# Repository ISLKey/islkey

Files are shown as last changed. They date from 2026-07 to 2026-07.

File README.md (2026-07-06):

# ISLKey

Access-control platform by **ISL Technologies** — ESP32-based door controllers with a
Windows flasher/commissioning tool and a companion mobile app.

## Repository layout

| Path | What it is | Stack |
|---|---|---|
| `islkey-firmware/` | Door-controller firmware — 4 board targets (relay-board, devkit, ttgo, wt32-eth01). Inputs (exit/door/fire/tamper), relay-driven lock, cloud HMAC device-auth, NimBLE. | ESP32 / PlatformIO / Arduino |
| `islkey-flasher/`  | Desktop flasher + serial commissioning tool. Flashes merged full-flash images at `0x0`, assigns serials, writes WiFi/API config over serial. | Electron / Node.js |
| `islkey-app/` | Companion door-access mobile app (NFC tap → resolve → unlock). | Flutter |
| `kicad/` | KiCad 8 schematic for the TTGO controller (inputs, relay lock output, monitored fire link, backup power). | KiCad |
| `wordpress/` | Drop-in integration notes for the isl-key WordPress plugin (device API / provisioning). | — |
| `make_wiring_diagram.py` | Generates the 4-sheet wiring/pinout PDF (`ISLKey-Wiring-Diagram.pdf`). | Python / matplotlib |
| `make_kicad_schematic.py` | Generates `kicad/ISLKey.kicad_sch` from source. | Python |

## Building

- **Firmware:** `cd islkey-firmware && python -m platformio run` (per-env in `platformio.ini`).
  After a rebuild, regenerate the merged images with `esptool merge_bin` (see below) — the
  flasher writes a **merged full-flash image at `0x0`**; a raw app image boot-loops the board.
- **Flasher:** `cd islkey-flasher && npm install && npm start` (or `npm run build` for the installer).
- **App:** `cd islkey-app && flutter pub get && flutter run`.

## Hardware notes

- On the **TTGO T-Display** target the TFT occupies GPIO 4/5/16/18/19/23, so door I/O is
  remapped: inputs GPIO 13/25/26/27, relays GPIO 32/33.
- The lock is switched via an **external opto-isolated relay module** (COM/NC), with a
  single **volt-free fire N/C contact in series** (hardware release, controller-independent)
  that is **opto-monitored to GPIO26** for fire detection + cable supervision. See `kicad/`
  and the wiring PDF.

## Not in this repo

Build artifacts (`.pio/`, `node_modules/`, Flutter `build/`, installer `dist/`) and
**operational secrets** — the per-device serial register / AP passwords (`islkey-flasher/serials/`)
and any real `.islkey` provisioning configs — are git-ignored.

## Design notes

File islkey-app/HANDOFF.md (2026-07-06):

# ISLKey Flutter — Developer Handoff

The **ISLKey** door-access app for ISLKey users (door holders). Built in the same
ecosystem and on the same architecture as **ISLShift** (the staff clock-in app).

Last updated: 2026-06-21.

---

## Current status

✅ **Builds on Android.** `flutter build apk --debug` → `build/app/outputs/flutter-apk/app-debug.apk`.
- `flutter analyze` → **0 errors / 0 warnings** (only cosmetic `withOpacity` / `prefer_const`
  deprecation *infos* remain — identical class of non-blocking notices to ISLShift).
- **Not yet run on a physical device.** NFC requires real hardware (emulators have no NFC);
  no Android device was connected at build time. Install with:
  ```
  flutter build apk --debug --target-platform android-arm64
  adb -s <deviceId> install -r -d build/app/outputs/flutter-apk/app-debug.apk
  ```
- iOS scaffolding exists but has not been built (no macOS/Xcode here). The NFC Tag Reading
  capability + `NFCReaderUsageDescription` Info.plist key must be added before an iOS build.

## Build environment

Same as ISLShift: Flutter 3.44.2 (`C:\src\flutter`), Android Studio JBR as `JAVA_HOME`,
`ANDROID_HOME` = `…\AppData\Local\Android\Sdk`. Package / applicationId:
**`com.isltechnologies.islkey`**.

Build workarounds baked into the repo (do not undo):
- `android/build.gradle.kts` forces every plugin subproject to `compileSdk = 36` via an
  `afterEvaluate` block registered **before** `evaluationDependsOn(":app")` — `nfc_manager`
  hardcodes an older compileSdk than its AndroidX deps require. Moving the block after
  `evaluationDependsOn` throws "project already evaluated".
- `AndroidManifest.xml` requests `INTERNET` + `NFC`, declares `android.hardware.nfc` as
  **not required** (installs on non-NFC phones), and **deliberately has no NFC tag-dispatch
  intent filters** — those make Android launch a second app instance on a stray tap. Tags are
  read via `nfc_manager` reader mode while the scan screen is open.

---

## Architecture (mirrors ISLShift)

```
lib/
  main.dart                     ProviderScope + MaterialApp, branding-driven theme
  theme.dart                    ISL palette + per-customer brand colour
  models/                       branding_data, user_profile, door, credential,
                                access_event, linked_site, unlock_result
  services/
    api_service.dart            HTTP; unwraps the ISL Core { ok, data } envelope
    nfc_service.dart            reader-mode scan → uppercase hex UID (no colons)
    secure_storage_service.dart token + profile + linked sites + offline caches
  providers/
    auth_provider.dart          setup / PIN login / sign out (Riverpod Notifier)
    doors_provider.dart         doors+credentials list, caching, unlock state machine
    sites_provider.dart         linked sites
  screens/                      splash, login, setup, home, nfc_scan,
                                unlock_result, history, profile, link_site
  widgets/shared_widgets.dart   logo, PIN pad, NFC pulse ring, access tile, etc.
```

Backend: `https://i-s-l.co.uk/wp-json`, namespace `islkey/v1`. Bearer token
(`Authorization: Bearer …`, query-param `?_isl_token=` fallback), 12-hour expiry → 401 →
re-auth with PIN. **All ISLKey responses are wrapped as `{ "ok": true, "data": {…} }`** —
`ApiService._handleResponse` unwraps `data` (this differs from ISLShift, which returned the
payload at the top level).

### Endpoints wired up (Layer 1 — App API)
`POST /invite/accept` · `POST /auth` · `POST /site/link` · `GET /tags/resolve` ·
`GET /me/doors` · `GET /me/credentials` · `GET /me/log` · `POST /doors/{id}/unlock`.
Customer branding comes from the shared ISL Core endpoint `GET /isl/v1/branding/{slug}`
(best-effort; falls back to ISLKey defaults so login never blocks on it).

### The unlock flow
1. **Primary (NFC, cloud-mediated):** tap phone to the door tag → read UID →
   `GET /tags/resolve?serial=` → verify the door is in the user's `/me/doors` list →
   `POST /doors/{id}/unlock` (method `NFC_TAP_CLOUD`) → backend queues the command to the
   ESP32 → show "Unlock sent" (the door opens when the ESP32 next polls; no push exists yet).
2. **Direct:** each door card also has an Unlock button that calls `/doors/{id}/unlock`
   directly for an authenticated user already at/near the door.

Unlock is blocked client-side when a door has no controller (`device_uuid == null`) or its
`fire_alarm_state == "ACTIVE"`; the backend re-checks regardless (403 / 422 / 404 handled).

---

## Deliberately NOT built (per the handover brief)

- **BLE direct-unlock fallback** — the brief marks this as the single blocking dependency:
  the ESP32 BLE service UUID and the signed offline-unlock token format must be agreed between
  firmware and app first. `/me/doors` + `/me/credentials` are already cached locally
  (`SecureStorageService`) so the cache the BLE path needs is in place. Add a `ble_service.dart`
  + an offline-detection branch in `doors_provider.resolveAndUnlock` once the format is agreed.
- **Change PIN** — the ISLKey API reference defines no `/me/pin` endpoint, so the profile
  screen omits it (add a tile once the backend exposes one).
- **Push notifications** — backend has no FCM/APNs yet; the app uses the timeout approach
  ("Unlock sent" after the queue accepts the command).

## Outstanding TODOs

1. **Release signing** — release builds currently use the debug key. Add a real keystore
   before shipping.
2. **App identity** — default Flutter launcher icon is still in place; add the ISLKey icon.
3. **On-device verification** — run the full flow (setup → PIN → tap-to-unlock → history) on a
   physical NFC Android device with a registered test tag (`58E104DD`, site `TE2001`).
4. **iOS** — add NFC capability + Info.plist usage string, then build.

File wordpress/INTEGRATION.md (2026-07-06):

# ISLKey `.islkey` Config Export — WordPress Integration

This adds a **Download .islkey Config File** button to the ISLKey provisioning-token
screen. The file is plain JSON consumed by the ISLKey Flasher's **Load .islkey File**
button. It is mechanism-agnostic — it only emits config; the flasher writes it to the
device over the commissioning serial link.

> The ISLKey WordPress plugin is **not part of this workspace** (it lives on the
> customer's site), so these changes are provided as drop-in snippets to merge into
> your `isl-key` plugin. They match the schema the new flasher expects.

Files to edit in the `isl-key` plugin:
- `admin/class-islkey-admin.php`
- `admin/views/devices.php`

---

## 1. `admin/class-islkey-admin.php`

### 1a — Register the handler (in `init()`, beside the other `admin_post` handlers)

```php
add_action( 'admin_post_islkey_download_config', array( __CLASS__, 'handle_download_config' ) );
```

### 1b — Store `board_type` when a token is generated

In `handle_generate_token()`, after:
```php
$expiry_hours = (int) ( $_POST['expiry_hours'] ?? 24 );
```
add:
```php
$board_type = sanitize_key( $_POST['board_type'] ?? 'relay-board' );
```
and add `board_type` to the existing `set_transient( 'islkey_fresh_token_' . get_current_user_id(), [...] )` array:
```php
'board_type' => $board_type,
```

### 1c — Add the download handler method (after `handle_generate_token()`)

```php
public static function handle_download_config() {
    check_admin_referer( 'islkey_download_config' );
    if ( ! current_user_can( 'manage_options' ) ) wp_die( 'Forbidden' );

    global $wpdb;

    $token       = sanitize_text_field( $_POST['token']       ?? '' );
    $customer_id = (int) ( $_POST['customer_id'] ?? 0 );
    $board_type  = sanitize_key( $_POST['board_type'] ?? 'relay-board' );

    // Validate token: exists, belongs to this customer, unconsumed, unexpired
    $pt = $wpdb->get_row( $wpdb->prepare(
        "SELECT * FROM `{$wpdb->prefix}islkey_provisioning_tokens`
         WHERE token = %s AND customer_id = %d AND consumed = 0 AND expires_at > NOW()",
        $token, $customer_id
    ) );
    if ( ! $pt ) {
        wp_die( 'Token not found, already consumed, or expired.' );
    }

    $door      = $pt->door_id ? ISLKey_Doors::get( $pt->door_id, $customer_id ) : null;
    $site      = ISLKey_Sites::get( $pt->site_id, $customer_id );
    $site_code = $site ? ( $site->site_code ?? sanitize_key( $site->site_name ) ) : '';

    $current_user = wp_get_current_user();

    $config = array(
        'islkey_config_version' => '1.0',
        'generated_at'          => gmdate( 'Y-m-d\TH:i:s\Z' ),
        'generated_by'          => 'ISL Admin — ' . $current_user->user_email,
        'expires_at'            => gmdate( 'Y-m-d\TH:i:s\Z', strtotime( $pt->expires_at ) ),

        'api' => array(
            'url'   => untrailingslashit( get_site_url() ),
            'token' => $token,
        ),

        'device' => array(
            'serial_number' => '',   // Flasher assigns from its own counter at flash time
            'board_type'    => $board_type,
            'door_name'     => $door ? $door->door_name : ( $site ? $site->site_name . ' Door' : 'Door' ),
            'site_name'     => $site ? $site->site_name : '',
            'site_code'     => $site_code,
            'door_id'       => $pt->door_id ? (int) $pt->door_id : 0,
            'site_id'       => $pt->site_id ? (int) $pt->site_id : 0,
            'customer_id'   => (int) $customer_id,
            'zone'          => $door ? ( $door->zone ?? '' ) : '',
        ),

        // Sensible defaults. The current device firmware applies api/door/site from
        // this file at commissioning; inputs/relays/door_behaviour use firmware
        // defaults and are overridable on the device provisioning page. (Panic input
        // types 5–7 require the separate "Protocols" firmware build.)
        'inputs' => array(
            'input_1_function' => 1, 'input_1_logic' => 1,
            'input_2_function' => 2, 'input_2_logic' => 0,
            'input_3_function' => 5, 'input_3_logic' => 1,
            'input_4_function' => 6, 'input_4_logic' => 1,
        ),
        'relays' => array(
            'relay_1_function' => 1, 'relay_1_pulse_ms' => 5000, 'relay_1_active_high' => true,
            'relay_2_function' => 0, 'relay_2_pulse_ms' => 2000, 'relay_2_active_high' => true,
        ),
        'door_behaviour' => array(
            'held_open_secs' => 60, 'forced_entry_detect' => true,
        ),
    );

    $safe_door = preg_replace( '/[^a-zA-Z0-9]+/', '', str_replace( ' ', '', $config['device']['door_name'] ) );
    $safe_site = preg_replace( '/[^a-zA-Z0-9]+/', '', str_replace( ' ', '', $config['device']['site_code'] ?: $config['device']['site_name'] ) );
    $filename  = "ISLKey-{$safe_site}-{$safe_door}-" . date( 'Ymd' ) . ".islkey";

    nocache_headers();
    header( 'Content-Type: application/json; charset=utf-8' );
    header( 'Content-Disposition: attachment; filename="' . $filename . '"' );
    header( 'X-Content-Type-Options: nosniff' );
    echo wp_json_encode( $config, JSON_PRETTY_PRINT | JSON_UNESCAPED_SLASHES );
    exit;
}
```

---

## 2. `admin/views/devices.php`

### 2a — Board-type selector in the Generate-Token form (before the submit button)

```php
<tr>
    <th>Board Type</th>
    <td>
        <select name="board_type" class="regular-text">
            <option value="relay-board">ISLKey Relay Board (WROOM dual relay)</option>
            <option value="devkit">ESP32 DevKit V1 (testing)</option>
            <option value="ttgo">TTGO T-Display (with LCD)</option>
            <option value="wt32-eth01">WT32-ETH01 (Ethernet + PoE)</option>
        </select>
    </td>
</tr>
```

### 2b — Download button in the fresh-token panel (after the "Device API Token" row)

```php
<tr>
    <th>Config File</th>
    <td>
        <form method="post" action="<?php echo esc_url( admin_url( 'admin-post.php' ) ); ?>" style="display:inline;">
            <?php wp_nonce_field( 'islkey_download_config' ); ?>
            <input type="hidden" name="action"      value="islkey_download_config">
            <input type="hidden" name="token"       value="<?php echo esc_attr( $fresh_token['token'] ); ?>">
            <input type="hidden" name="customer_id" value="<?php echo esc_attr( $customer_id ); ?>">
            <input type="hidden" name="board_type"  value="<?php echo esc_attr( $fresh_token['board_type'] ?? 'relay-board' ); ?>">
            <button type="submit" class="button button-primary">⬇ Download .islkey Config File</button>
        </form>
        <p class="description">
            Load this file into the ISLKey Flasher. It pre-populates board type, API URL,
            token, door name and site code — only WiFi is entered on the device.
        </p>
    </td>
</tr>
```

---

## Notes for the new firmware/flasher

- `device.serial_number` is intentionally `""` — the flasher assigns the serial from its
  local counter (`serials/next-serial.txt`) at flash time and logs it to the asset register.
- The flasher writes `api.url`, `api.token`, `device.door_name`, `device.site_code` (plus the
  generated serial + AP password) to the device over the serial commissioning link
  (`ISLKEY-PROV:{json}` → `ISLKEY-ACK`). The device stores them in NVS and pre-fills its
  provisioning page, so the installer only enters WiFi SSID + password.
- This export does **not** use the old `buildNVSImage` / `checkFlasherPayload` path from the
  v1.0 build guide — that was for the previous firmware and has been superseded.

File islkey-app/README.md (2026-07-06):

# islkey

A new Flutter project.

## Getting Started

This project is a starting point for a Flutter application.

A few resources to get you started if this is your first Flutter project:

- [Learn Flutter](https://docs.flutter.dev/get-started/learn-flutter)
- [Write your first Flutter app](https://docs.flutter.dev/get-started/codelab)
- [Flutter learning resources](https://docs.flutter.dev/reference/learning-resources)

For help getting started with Flutter development, view the
[online documentation](https://docs.flutter.dev/), which offers tutorials,
samples, guidance on mobile development, and a full API reference.

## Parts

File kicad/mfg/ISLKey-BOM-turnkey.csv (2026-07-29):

Item | Refs | Qty | Value | Footprint | Type | Manufacturer | MPN | Distributor | Distributor PN / Link | Notes
1 | R1,R3,R6,R7,R8 | 5 | 1k | R_0805 | SMD | Yageo | RC0805FR-071KL | LCSC | C17513 | 1% 0805 thick film; Digikey 311-1.00KCRCT-ND
2 | R2,R4 | 2 | 10k | R_0805 | SMD | Yageo | RC0805FR-0710KL | LCSC | C17414 | 1% 0805
3 | R5 | 1 | 2k2 | R_0805 | SMD | Yageo | RC0805FR-072K2L | LCSC | C4190 | 1% 0805 (opto LED series)
4 | C2,C3,C6 | 3 | 100nF | C_0805 | SMD | Samsung | CL21B104KBCNNNC | LCSC | C1525 | 50V X7R decoupling
5 | C1 | 1 | 100uF 16V | CP_Elec_6.3x5.3 | SMD | Panasonic | EEE-1CA101P | Digikey | PCE3903CT-ND | SMD alu 6.3mm
6 | C5 | 1 | 100uF 25V | CP_Elec_6.3x5.3 | SMD | Panasonic | EEE-1EA101P | Digikey | PCE3915CT-ND | SMD alu 6.3mm (12V bulk)
7 | C4 | 1 | 100uF 100V | CP_Elec_10x10.5 | SMD | Nichicon | UCM2A101MNL1GS | Digikey | 493-UCM2A101MNL1GS | 100V SMD alu 10mm can (bridge bulk); verify height/dia vs footprint
8 | D1,D2 | 2 | 1N4007 (M7) | D_SMA | SMD | Diodes Inc | M7-13-F | LCSC | C95872 | 1A 1000V SMA (relay flyback)
9 | D3 | 1 | PWR (red) | LED_0805 | SMD | Kingbright | APT2012SURCK | LCSC | C2286 | Power indicator LED (red)
10 | D4,D5 | 2 | GRN | LED_0805 | SMD | Kingbright | APT2012LZGCK | LCSC | C72043 | Relay-status LEDs (green)
11 | Q1,Q2 | 2 | PN2222A | TO-92_Inline | THT | onsemi | PN2222ABU | Digikey | PN2222ABU-ND | NPN relay driver
12 | K1,K2 | 2 | SRD-05VDC-SL-C | Relay_SPDT_SANYOU_SRD | THT | Songle | SRD-05VDC-SL-C | LCSC | C39487 | 5V coil SPDT 10A relay
13 | U1 | 1 | PC817 | DIP-4_W7.62mm | THT | LiteOn | LTV-817 | LCSC | C6553 | Optocoupler (fire monitor); Sharp PC817 equivalent
14 | U3 | 1 | TMR 10-2412WIR | Converter_DCDC_TRACO_TMR10 | THT | Traco Power | TMR 10-2412WIR | Digikey | https://www.digikey.com/short/tmr10-2412wir | 9-36V -> iso 12V 10W SIP-8; Mouser also
15 | U4 | 1 | TSR 1-2450 | Converter_DCDC_TRACO_TSR-1 | THT | Traco Power | TSR 1-2450 | LCSC | C6886877 | 12->5V 1A SIP-3 buck; Digikey too
16 | U5 | 1 | DS3231SN | SOIC-16W_7.5x10.3 | SMD | Analog Devices (Maxim) | DS3231SN# | Digikey | DS3231SN#-ND | NOTE: 16-SOIC part is DS3231SN (schematic label says DS3231M; the SO-8 'M' does NOT fit this footprint)
17 | BR1 | 1 | KBU4M | Diode_Bridge_Vishay_KBU | THT | Comchip | KBU4M-G | Digikey | 641-1373-ND | 4A 1000V bridge rectifier
18 | F1 (clips) | 2 | Fuse clip 5x20 | Fuseholder_Clip-5x20mm_Keystone_3512 | THT | Keystone | 3512 | Digikey | 36-3512-ND | TWO clips make one holder (F1)
19 | F1 (fuse) | 1 | T2A 5x20 | - | - | Littelfuse | 0217002.MXP | Digikey | F2452-ND | 2A slow-blow 5x20mm glass fuse
20 | BT1 | 1 | 18650 holder | BatteryHolder_Keystone_1042 | SMD | Keystone | 1042 | Digikey | 36-1042-ND | SMT 1x18650 holder
21 | BT3 | 1 | CR2032 holder | BatteryHolder_Keystone_3002 | SMD | Keystone | 3002 | Digikey | 36-3002-ND | SMT CR2032 retainer (RTC backup)
22 | J3,J4,J5,J8,J10,J11 | 6 | Screw term 2-pin | TerminalBlock MKDS 5.08 1x02 | THT | Phoenix Contact | MKDS 1,5/ 2-5.08 (1715721) | Digikey | 277-1247-ND | 5.08mm 2-way 17.5A
23 | J6,J7 | 2 | Screw term 3-pin | TerminalBlock MKDS 5.08 1x03 | THT | Phoenix Contact | MKDS 1,5/ 3-5.08 (1715734) | Digikey | 277-1248-ND | 5.08mm 3-way (relay COM/NO/NC)
24 | J9,J13,J15 | 3 | Header 1x02 2.54 | PinHeader_1x02_2.54mm | THT | Wurth | 61300211121 | LCSC | C124378 | 2-pin 2.54mm header
25 | J9,J15 shunts | 2 | Jumper shunt | - | - | Sullins | SPC02SYAN | Digikey | S9337-ND | 2.54mm jumper caps for the FIRE LINK + DCDC ON headers
26 | H1-H4 | 4 | M3 mount | MountingHole_3.2mm | Hardware | - | M3 screw/standoff | - | - | Not populated by assembler; mechanical M3
NOTE |  |  |  |  |  |  |  |  |  | M1 (TTGO T-Display) intentionally omitted - customer-sourced, fits into headers post-assembly. Distributor PNs are indicative; confirm current stock/PN before ordering.

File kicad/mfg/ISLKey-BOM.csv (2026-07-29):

Refs | Value | Footprint | Qty
BR1 | KBU4M (4A) | Diode_THT:Diode_Bridge_Vishay_KBU | 1
BT1 | 18650 | Battery:BatteryHolder_Keystone_1042_1x18650 | 1
BT3 | CR2032 | Battery:BatteryHolder_Keystone_3002_1x2032 | 1
C1 | 100uF/16V | Capacitor_SMD:CP_Elec_6.3x5.3 | 1
C2,C3,C6 | 100nF | Capacitor_SMD:C_0805_2012Metric | 3
C4 | 100uF/100V | Capacitor_SMD:CP_Elec_10x10.5 | 1
C5 | 100uF/25V | Capacitor_SMD:CP_Elec_6.3x5.3 | 1
D1,D2 | 1N4007 | Diode_SMD:D_SMA | 2
D3 | PWR | LED_SMD:LED_0805_2012Metric | 1
D4,D5 | GRN | LED_SMD:LED_0805_2012Metric | 2
F1 | T2A | Fuse:Fuseholder_Clip-5x20mm_Keystone_3512_Inline_P23.62x7.27mm_D1.02x1.57mm_Horizontal | 1
J3 | Exit btn | TerminalBlock_Phoenix:TerminalBlock_Phoenix_MKDS-1,5-2-5.08_1x02_P5.08mm_Horizontal | 1
J4 | Door contact | TerminalBlock_Phoenix:TerminalBlock_Phoenix_MKDS-1,5-2-5.08_1x02_P5.08mm_Horizontal | 1
J5 | Tamper | TerminalBlock_Phoenix:TerminalBlock_Phoenix_MKDS-1,5-2-5.08_1x02_P5.08mm_Horizontal | 1
J6 | LOCK COM/NO/NC | TerminalBlock_Phoenix:TerminalBlock_Phoenix_MKDS-1,5-3-5.08_1x03_P5.08mm_Horizontal | 1
J7 | AUX COM/NO/NC | TerminalBlock_Phoenix:TerminalBlock_Phoenix_MKDS-1,5-3-5.08_1x03_P5.08mm_Horizontal | 1
J8 | Fire volt-free | TerminalBlock_Phoenix:TerminalBlock_Phoenix_MKDS-1,5-2-5.08_1x02_P5.08mm_Horizontal | 1
J9 | Fire link COM-Fire | Connector_PinHeader_2.54mm:PinHeader_1x02_P2.54mm_Vertical | 1
J10 | 5-60V AC/DC IN | TerminalBlock_Phoenix:TerminalBlock_Phoenix_MKDS-3-2-5.08_1x02_P5.08mm_Horizontal | 1
J11 | 12V OUT (lock/aux) | TerminalBlock_Phoenix:TerminalBlock_Phoenix_MKDS-3-2-5.08_1x02_P5.08mm_Horizontal | 1
J13 | TTGO batt pads | Connector_PinHeader_2.54mm:PinHeader_1x02_P2.54mm_Vertical | 1
J15 | DCDC ON link (Ctrl-+Vin) | Connector_PinHeader_2.54mm:PinHeader_1x02_P2.54mm_Vertical | 1
K1,K2 | SRD-05VDC-SL-C | Relay_THT:Relay_SPDT_SANYOU_SRD_Series_Form_C | 2
M1 | TTGO T-Display | ISLKey:TTGO_ESP32_TDisplay_v1.1 | 1
Q1,Q2 | PN2222A | Package_TO_SOT_THT:TO-92_Inline | 2
R1,R3,R6-R8 | 1k | Resistor_SMD:R_0805_2012Metric | 5
R2,R4 | 10k | Resistor_SMD:R_0805_2012Metric | 2
R5 | 2k2 | Resistor_SMD:R_0805_2012Metric | 1
U1 | PC817 | Package_DIP:DIP-4_W7.62mm | 1
U3 | TMR10-2412WIR | Converter_DCDC:Converter_DCDC_TRACO_TMR10-24xxWIR_48xxWIR_72xxWIR_THT | 1
U4 | TSR-1-2450 | Converter_DCDC:Converter_DCDC_TRACO_TSR-1_THT | 1
U5 | DS3231M | Package_SO:SOIC-16W_7.5x10.3mm_P1.27mm | 1

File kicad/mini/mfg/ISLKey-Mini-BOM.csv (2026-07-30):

Item | Designator | Qty | Value | Footprint | Manufacturer | MPN | Supplier | Supplier PN | Placement | Notes
1 | R1,R4,R7 | 3 | 1k | R_0805 | Yageo | RC0805FR-071KL | LCSC | C17513 | SMD | 1% 1/8W (R4=PWR-LED, R7=relay-LED, R1=relay-base)
2 | R2,R6 | 2 | 10k | R_0805 | Yageo | RC0805FR-0710KL | LCSC | C17414 | SMD | R2=base pulldown, R6=FB bottom
3 | R5 | 1 | 53.6k | R_0805 | Yageo | RC0805FR-0753K6L | Digikey | 311-53.6KCRCT-ND | SMD | buck FB top divider (5V out)
4 | C1,C2,C5,C6 | 4 | 100nF | C_0805 | Samsung | CL21B104KBCNNNC | LCSC | C1525 | SMD | 50V X7R decoupling
5 | C4 | 1 | 22uF/25V | CP_Elec_6.3x5.3 | Panasonic | EEE-1EA220P | Digikey | PCE3908CT-ND | SMD | SMD alu, bridge bulk
6 | C7 | 1 | 22uF/16V | CP_Elec_6.3x5.3 | Panasonic | EEE-1CA220P | Digikey | PCE3903CT-ND | SMD | SMD alu, 5V out
7 | L1 | 1 | 4.7uH | L_6.3x6.3_H3 | Sunlord | SWPA6045S4R7MT | LCSC | C167218 | SMD | >=2A shielded power inductor
8 | U2 | 1 | AP63203WU | TSOT-23-6 | Diodes Inc | AP63203WU-7 | Digikey | AP63203WU-7DICT-ND | SMD | 3.8-32V -> 5V 2A sync buck
9 | BR1 | 1 | ABS10 | Diode_Bridge_Diotec_ABS | Diotec | ABS10 | LCSC | C86089 | SMD | 1A 1000V SMD bridge (AC or DC in)
10 | F1 | 1 | 500mA PTC | Fuse_1812 | Bourns | MF-MSMF050-2 | Digikey | MF-MSMF050-2CT-ND | SMD | resettable PTC 1812
11 | D1 | 1 | 1N4148 | SOD-123 | Diodes Inc | 1N4148W-7-F | LCSC | C81598 | SMD | relay-coil flyback
12 | Q1 | 1 | MMBT2222A | SOT-23 | onsemi | MMBT2222ALT1G | LCSC | C8286 | SMD | relay driver NPN
13 | D3 | 1 | PWR (red) | LED_0805 | Kingbright | APT2012SURCK | LCSC | C2286 | SMD | power indicator LED
14 | D4 | 1 | GRN | LED_0805 | Kingbright | APT2012LZGCK | LCSC | C72043 | SMD | relay-status LED
15 | K1 | 1 | G6E (2A) | Relay_SPDT_Omron_G6E | Omron | G6E-134P-ST-US DC5 | Digikey | Z8917-ND | THT | SPDT 2A -- ORDER THE DC5 (5V coil) VARIANT
16 | J1,J3 | 2 | Term 2-pin | PT-1,5/2-3.5-H | Phoenix Contact | PT 1,5/2-3,5-H (1935161) | Digikey | 277-9524-ND | THT | 3.5mm horizontal-entry (J1=12V in, J3=EXIT)
17 | J2 | 1 | Term 3-pin | PT-1,5/3-3.5-H | Phoenix Contact | PT 1,5/3-3,5-H (1935174) | Digikey | 277-9525-ND | THT | 3.5mm horizontal-entry (LOCK COM/NO/NC)
18 | M1 | 1 | TTGO T-Display | TTGO_ESP32_TDisplay_v1.1 | LILYGO | T-Display ESP32 (16MB) | customer-sourced |  | DNP | DO NOT PLACE at PCBA -- customer-sourced module, fits headers post-assembly
NOTE |  |  |  |  |  |  |  |  |  | Supplier PNs indicative -- confirm stock before ordering. Confirm the Phoenix PT-H horizontal order numbers. K1: order the 5V-coil (DC5) G6E.

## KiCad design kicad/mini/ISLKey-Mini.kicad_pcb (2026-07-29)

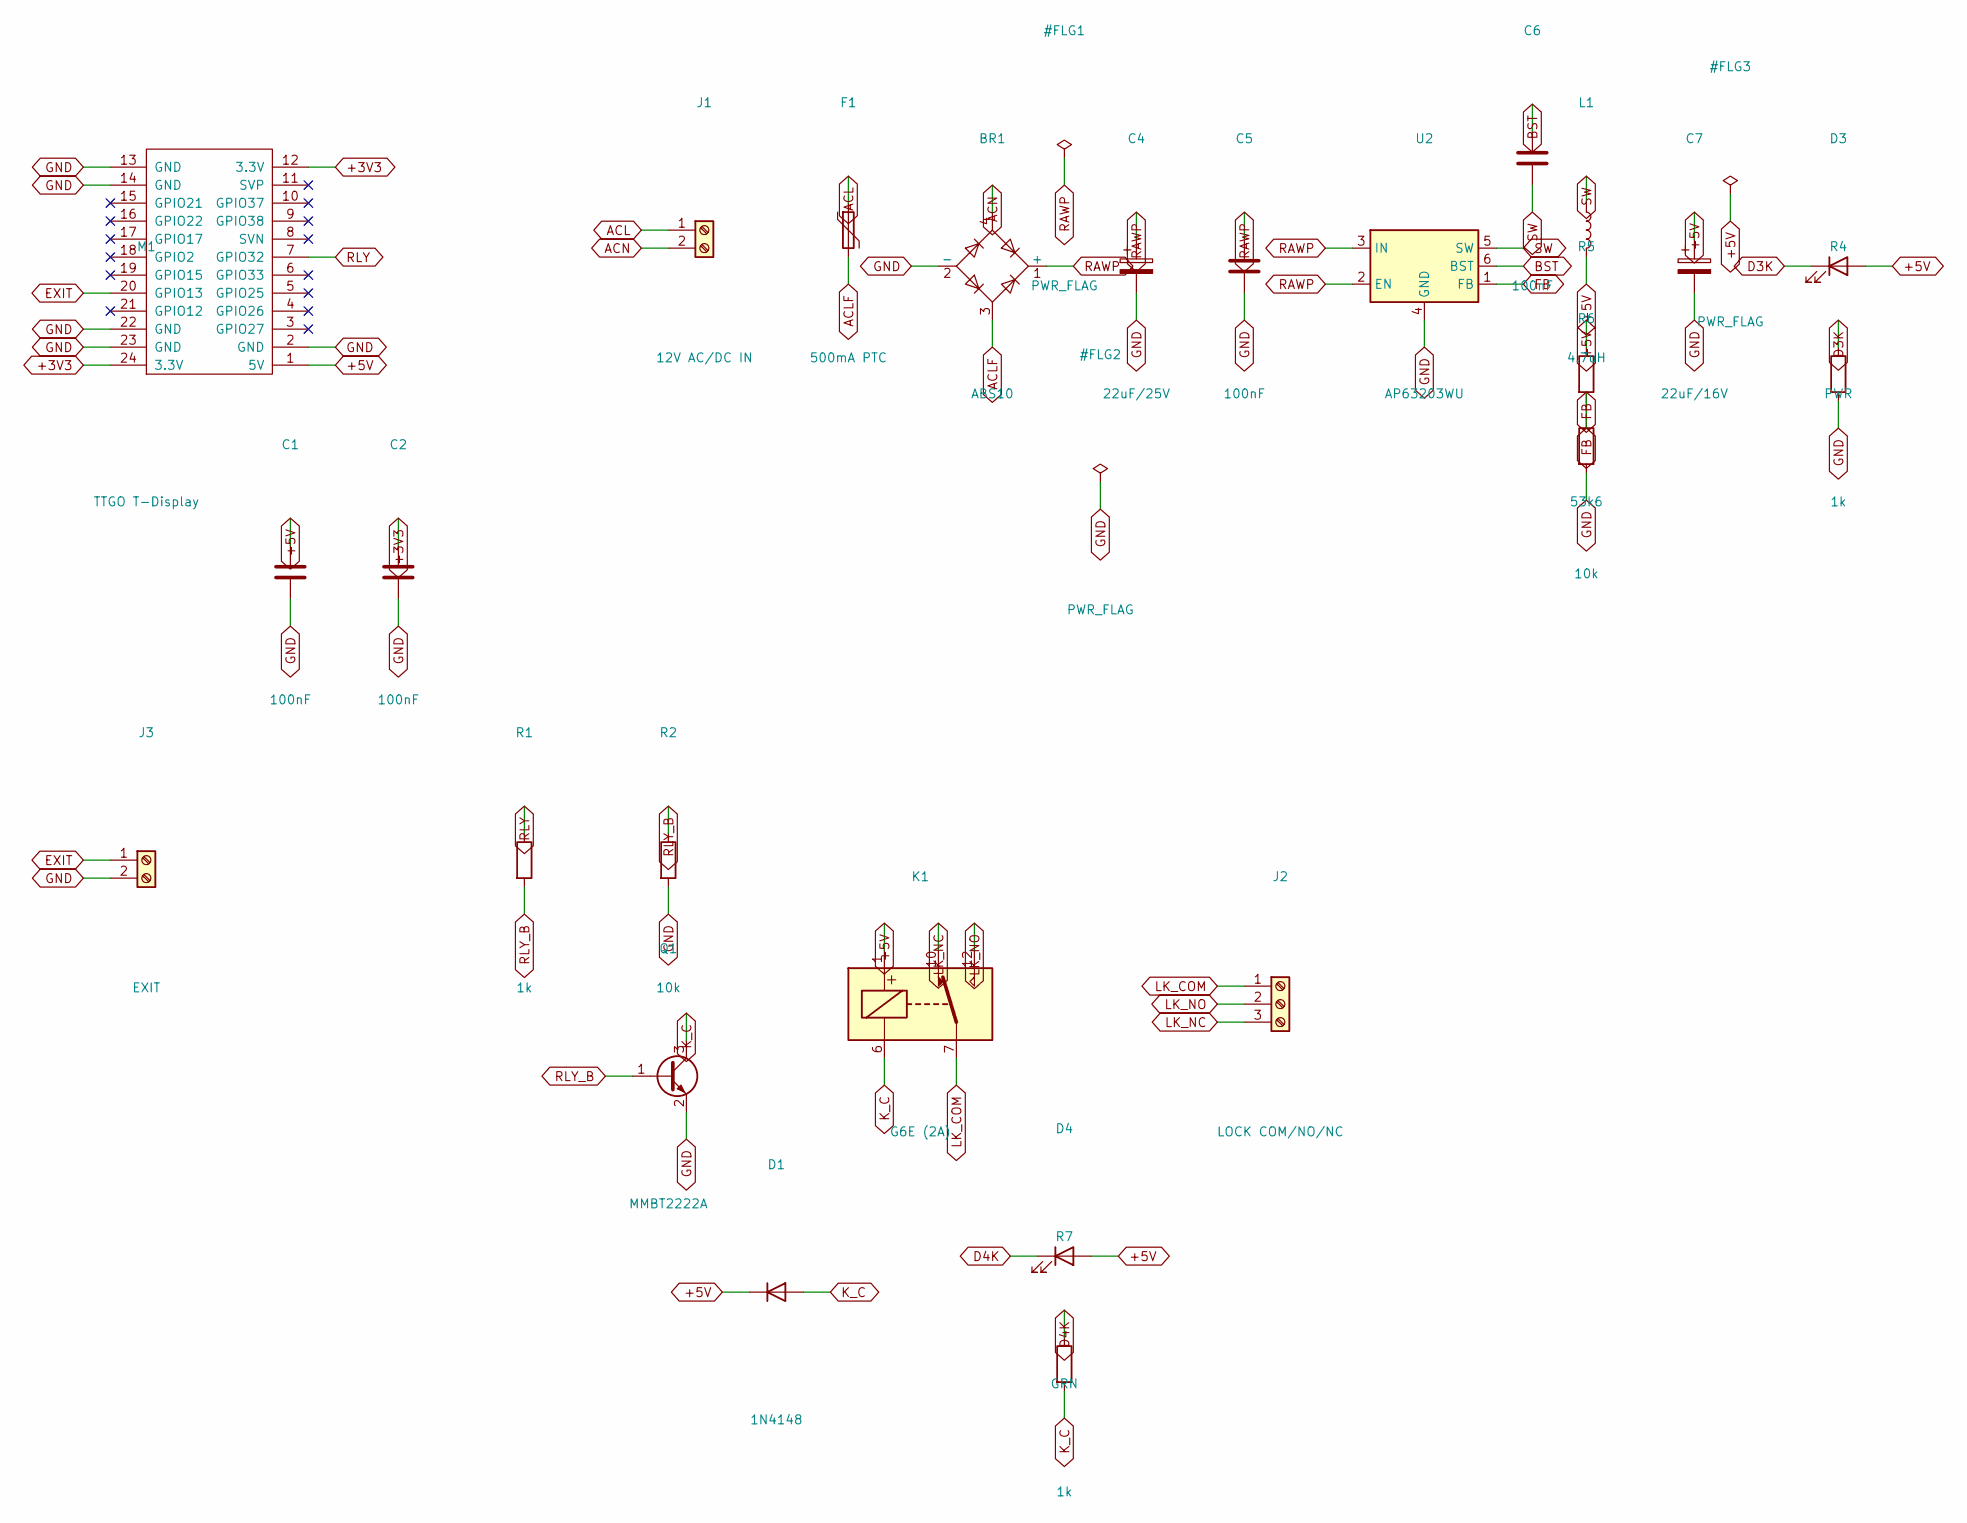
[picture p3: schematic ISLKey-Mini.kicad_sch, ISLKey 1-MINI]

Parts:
BR1: ABS10; Diode_Bridge_Diotec_ABS
C1, C2, C5, C6: 100nF; C_0805_2012Metric
C4: 22uF/25V; CP_Elec_6.3x5.3
C7: 22uF/16V; CP_Elec_6.3x5.3
D1: 1N4148; D_SOD-123
D3: PWR; LED_0805_2012Metric
D4: GRN; LED_0805_2012Metric
F1: 500mA PTC; Fuse_1812_4532Metric
J1: 12V AC/DC IN; TerminalBlock_Phoenix_PT-1,5-2-3.5-H_1x02_P3.50mm_Horizontal
J2: LOCK COM/NO/NC; TerminalBlock_Phoenix_PT-1,5-3-3.5-H_1x03_P3.50mm_Horizontal
J3: EXIT; TerminalBlock_Phoenix_PT-1,5-2-3.5-H_1x02_P3.50mm_Horizontal
K1: G6E (2A); Relay_SPDT_Omron_G6E
L1: 4.7uH; L_6.3x6.3_H3
M1: TTGO T-Display; TTGO_ESP32_TDisplay_v1.1
Q1: MMBT2222A; SOT-23
R1, R4, R7: 1k; R_0805_2012Metric
R2, R6: 10k; R_0805_2012Metric
R5: 53k6; R_0805_2012Metric
U2: AP63203WU; TSOT-23-6

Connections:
+3V3: C2.1, M1.12 (3.3V), M1.24 (3.3V)
+5V: C1.1, C7.1, D1.1 (K), D3.2 (A), D4.2 (A), K1.1, L1.2, M1.1 (5V), R5.1
ACL: F1.1, J1.1
ACLF: BR1.3, F1.2
ACN: BR1.4, J1.2
BST: C6.1, U2.6 (BST)
D3K: D3.1 (K), R4.1
D4K: D4.1 (K), R7.1
EXIT: J3.1, M1.20 (GPIO13)
FB: R5.2, R6.1, U2.1 (FB)
GND: BR1.2 (-), C1.2, C2.2, C4.2, C5.2, C7.2, J3.2, M1.2 (GND), M1.13 (GND), M1.14 (GND), M1.22 (GND), M1.23 (GND), Q1.2 (E), R2.2, R4.2, R6.2, U2.4 (GND)
K_C: D1.2 (A), K1.6, Q1.3 (C), R7.2
LK_COM: J2.1, K1.7
LK_NC: J2.3, K1.10
LK_NO: J2.2, K1.12
RAWP: BR1.1 (+), C4.1, C5.1, U2.2 (EN), U2.3 (IN)
RLY: M1.7 (GPIO32), R1.1
RLY_B: Q1.1 (B), R1.2, R2.1
SW: C6.2, L1.1, U2.5 (SW)

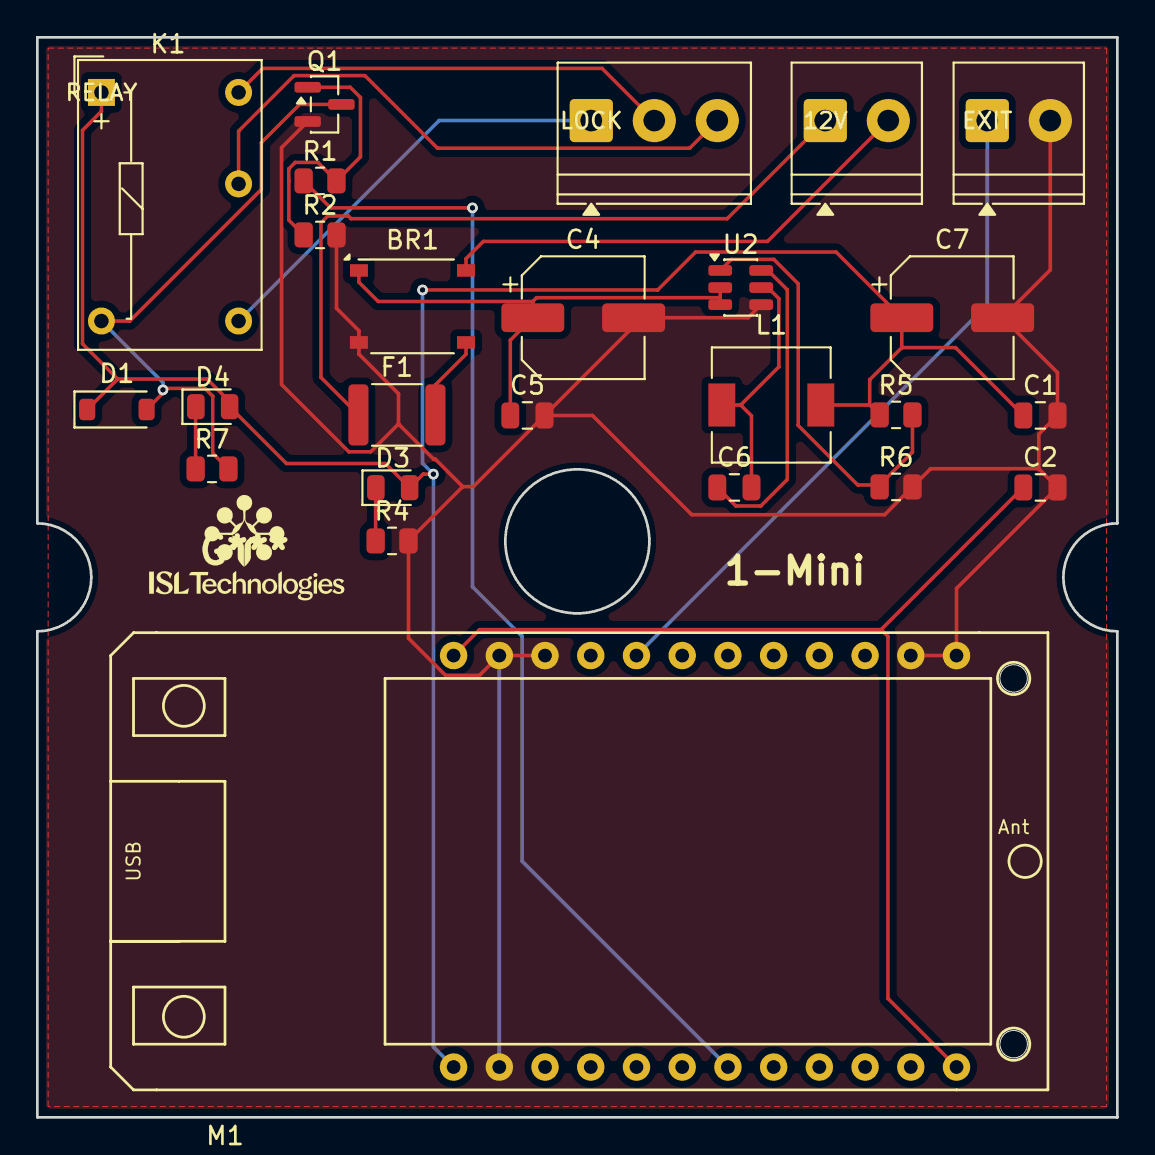
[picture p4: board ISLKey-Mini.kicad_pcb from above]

Board: 2 copper layers, 60.0 x 60.0 mm, 25 parts (0 on the bottom side), 19 nets.

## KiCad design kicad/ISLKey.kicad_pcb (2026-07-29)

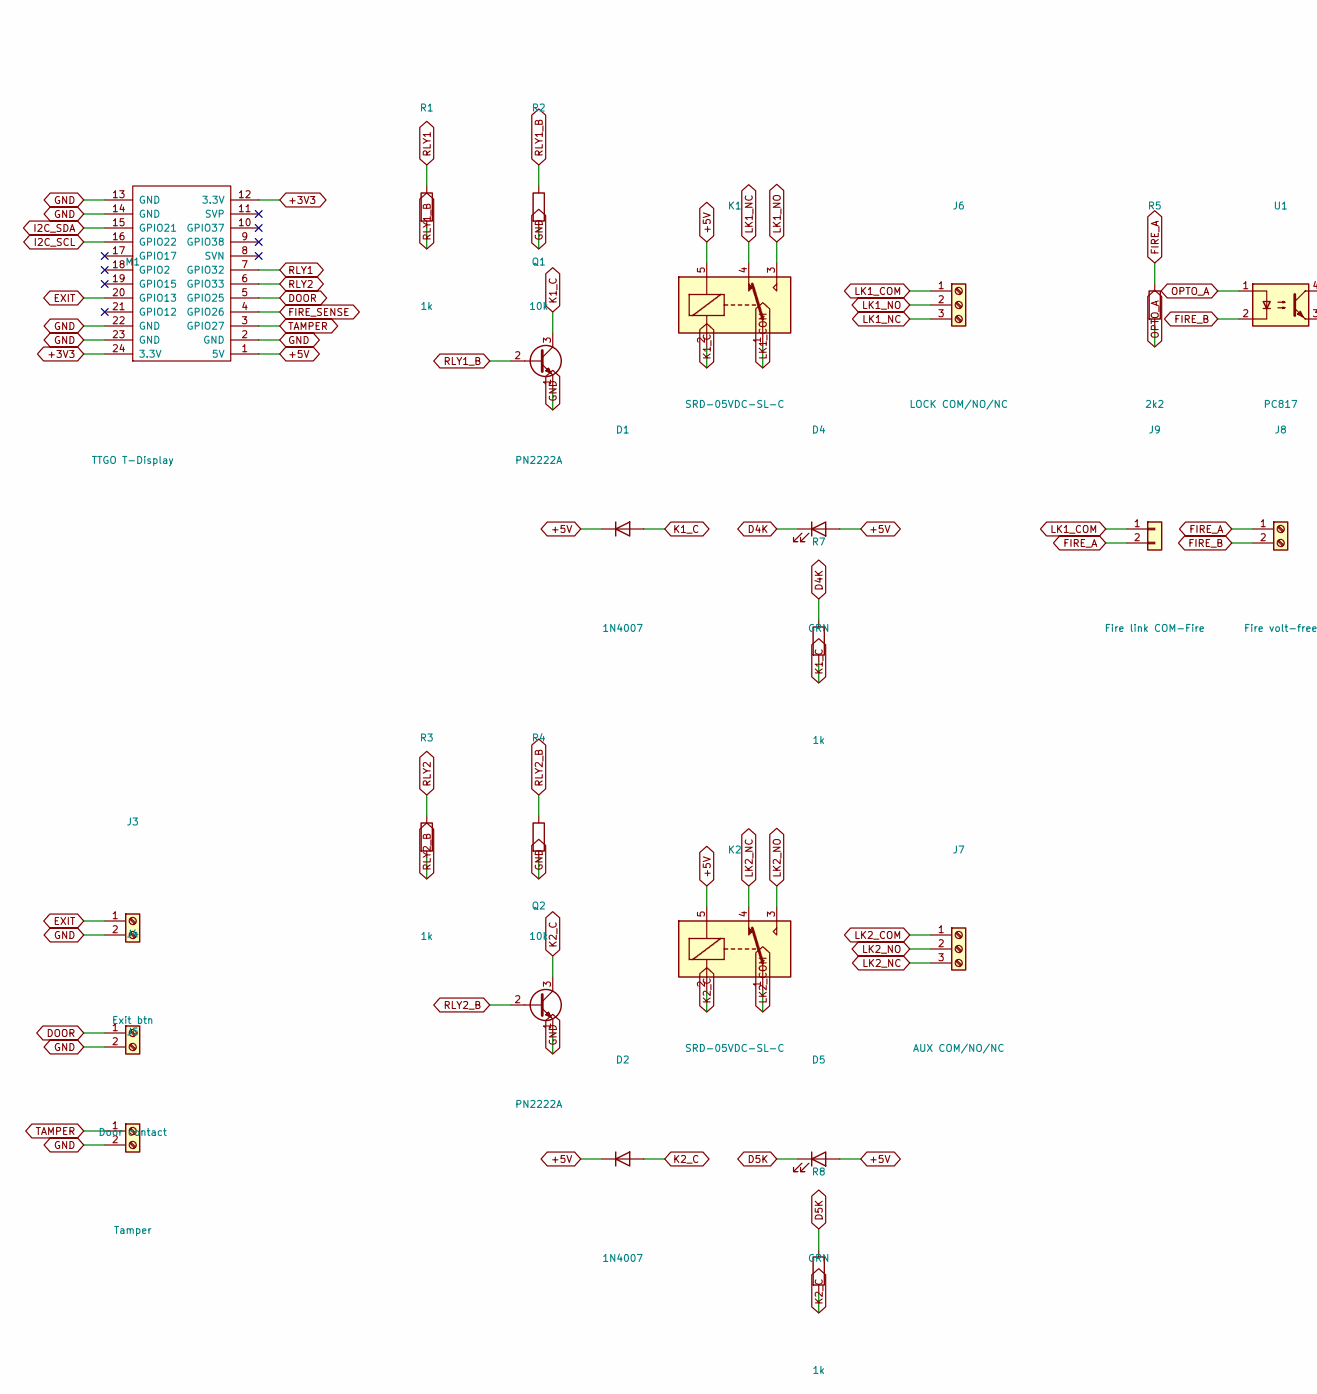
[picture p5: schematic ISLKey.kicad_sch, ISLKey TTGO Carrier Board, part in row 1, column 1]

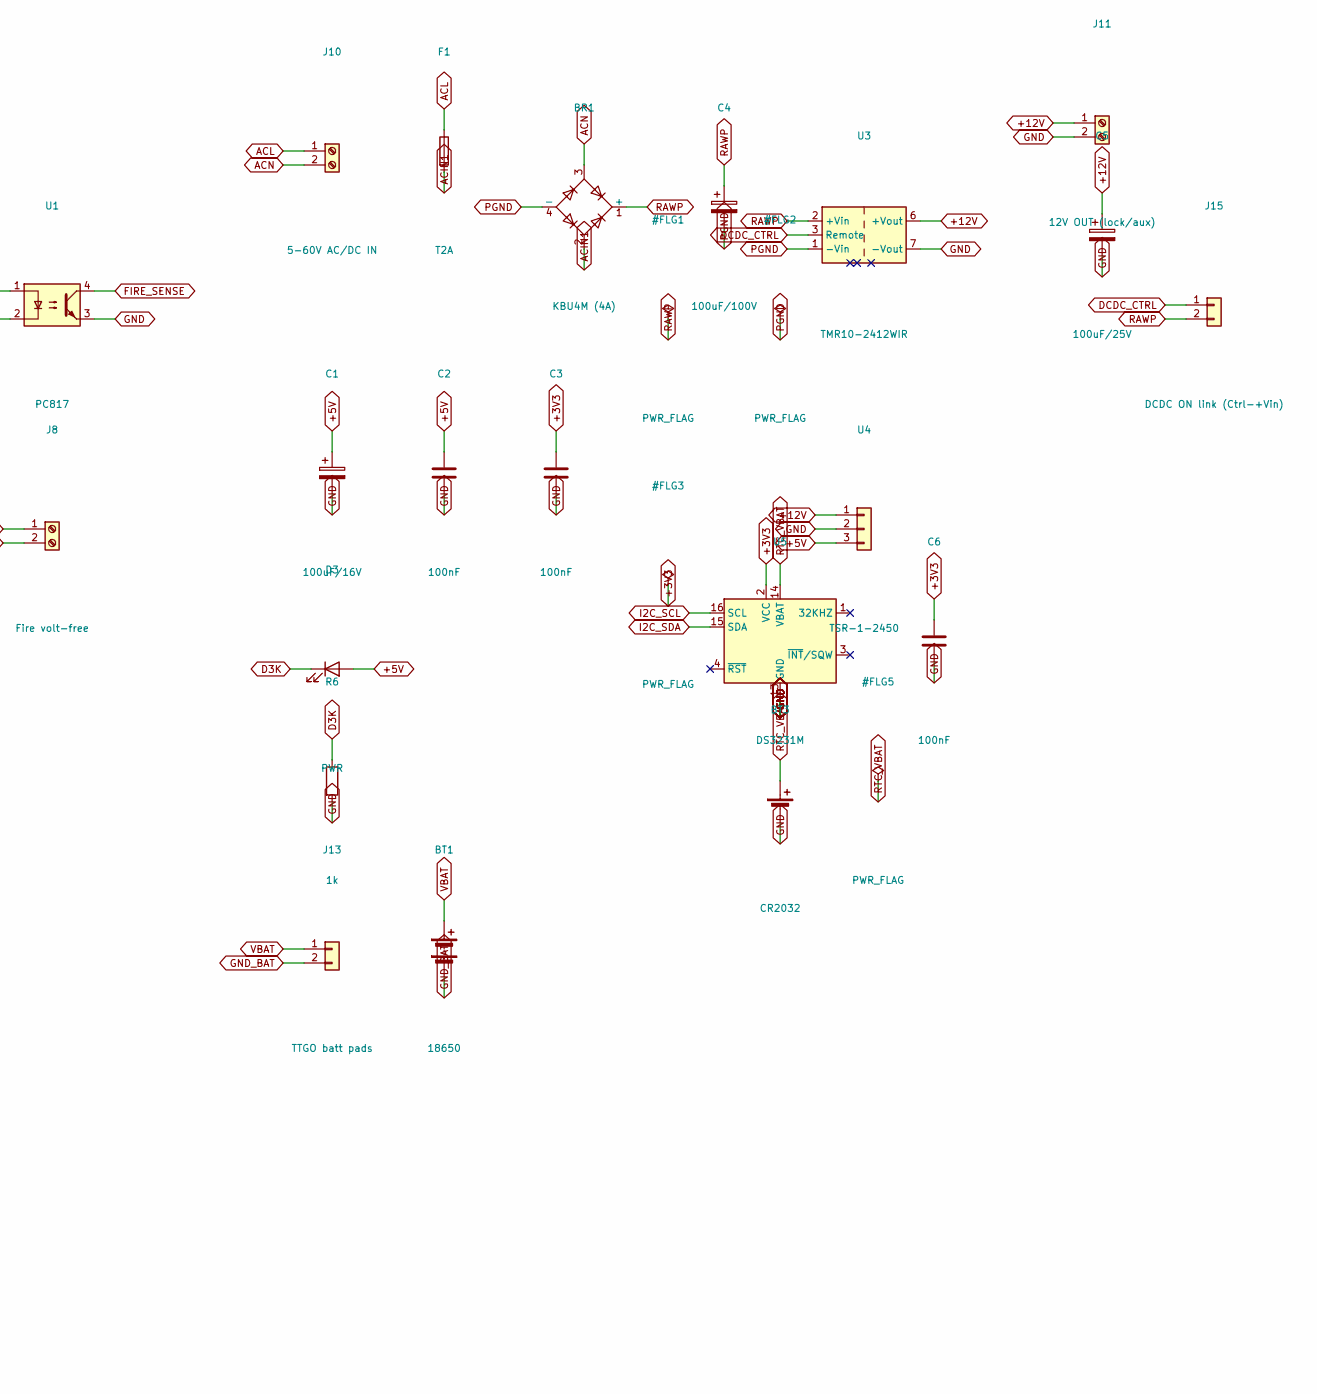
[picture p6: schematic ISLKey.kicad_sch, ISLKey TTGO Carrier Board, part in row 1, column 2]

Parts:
BR1: KBU4M (4A); Diode_Bridge_Vishay_KBU
BT1: 18650; BatteryHolder_Keystone_1042_1x18650
BT3: CR2032; BatteryHolder_Keystone_3002_1x2032
C1: 100uF/16V; CP_Elec_6.3x5.3
C2, C3, C6: 100nF; C_0805_2012Metric
C4: 100uF/100V; CP_Elec_10x10.5
C5: 100uF/25V; CP_Elec_6.3x5.3
D1, D2: 1N4007; D_SMA
D3: PWR; LED_0805_2012Metric
D4, D5: GRN; LED_0805_2012Metric
F1: T2A; Fuseholder_Clip-5x20mm_Keystone_3512_Inline_P23.62x7.27mm_D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
J3: Exit btn; TerminalBlock_Phoenix_MKDS-1,5-2-5.08_1x02_P5.08mm_Horizont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
J4: Door contact; TerminalBlock_Phoenix_MKDS-1,5-2-5.08_1x02_P5.08mm_Horizont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
J5: Tamper; TerminalBlock_Phoenix_MKDS-1,5-2-5.08_1x02_P5.08mm_Horizont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
J6: LOCK COM/NO/NC; TerminalBlock_Phoenix_MKDS-1,5-3-5.08_1x03_P5.08mm_Horizont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
J7: AUX COM/NO/NC; TerminalBlock_Phoenix_MKDS-1,5-3-5.08_1x03_P5.08mm_Horizont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
J8: Fire volt-free; TerminalBlock_Phoenix_MKDS-1,5-2-5.08_1x02_P5.08mm_Horizont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
J9: Fire link COM-Fire; PinHeader_1x02_P2.54mm_Vertical
J10: 5-60V AC/DC IN; TerminalBlock_Phoenix_MKDS-3-2-5.08_1x02_P5.08mm_Horizontal
J11: 12V OUT (lock/aux); TerminalBlock_Phoenix_MKDS-3-2-5.08_1x02_P5.08mm_Horizontal
J13: TTGO batt pads; PinHeader_1x02_P2.54mm_Vertical
J15: DCDC ON link (Ctrl-+Vin); PinHeader_1x02_P2.54mm_Vertical
K1, K2: SRD-05VDC-SL-C; Relay_SPDT_SANYOU_SRD_Series_Form_C
M1: TTGO T-Display; TTGO_ESP32_TDisplay_v1.1
Q1, Q2: PN2222A; TO-92_Inline
R1, R3, R6, R7, R8: 1k; R_0805_2012Metric
R2, R4: 10k; R_0805_2012Metric
R5: 2k2; R_0805_2012Metric
U1: PC817; DIP-4_W7.62mm
U3: TMR10-2412WIR; Converter_DCDC_TRACO_TMR10-24xxWIR_48xxWIR_72xxWIR_THT
U4: TSR-1-2450; Converter_DCDC_TRACO_TSR-1_THT
U5: DS3231M; SOIC-16W_7.5x10.3mm_P1.27mm

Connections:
+3V3: C3.1, C6.1, M1.12 (3.3V), M1.24 (3.3V), U5.2 (VCC)
+5V: C1.1, C2.1, D1.1 (K), D2.1 (K), D3.2 (A), D4.2 (A), D5.2 (A), K1.5, K2.5, M1.1 (5V), U4.3
+12V: C5.1, J11.1, U3.6 (+Vout), U4.1
ACIN1: BR1.2, F1.2
ACL: F1.1, J10.1
ACN: BR1.3, J10.2
D3K: D3.1 (K), R6.1
D4K: D4.1 (K), R7.1
D5K: D5.1 (K), R8.1
DCDC_CTRL: J15.1, U3.3 (Remote)
DOOR: J4.1, M1.5 (GPIO25)
EXIT: J3.1, M1.20 (GPIO13)
FIRE_A: J8.1, J9.2, R5.1
FIRE_B: J8.2, U1.2
FIRE_SENSE: M1.4 (GPIO26), U1.4
GND: BT3.2 (-), C1.2, C2.2, C3.2, C5.2, C6.2, J3.2, J4.2, J5.2, J11.2, M1.2 (GND), M1.13 (GND), M1.14 (GND), M1.22 (GND), M1.23 (GND), Q1.1 (E), Q2.1 (E), R2.2, R4.2, R6.2, U1.3, U3.7 (-Vout), U4.2, U5.5 (GND), U5.6 (GND), U5.7 (GND), U5.8 (GND), U5.9 (GND), U5.10 (GND), U5.11 (GND), U5.12 (GND), U5.13 (GND)
GND_BAT: BT1.2 (-), J13.2
I2C_SCL: M1.16 (GPIO22), U5.16 (SCL)
I2C_SDA: M1.15 (GPIO21), U5.15 (SDA)
K1_C: D1.2 (A), K1.2, Q1.3 (C), R7.2
K2_C: D2.2 (A), K2.2, Q2.3 (C), R8.2
LK1_COM: J6.1, J9.1, K1.1
LK1_NC: J6.3, K1.4
LK1_NO: J6.2, K1.3
LK2_COM: J7.1, K2.1
LK2_NC: J7.3, K2.4
LK2_NO: J7.2, K2.3
OPTO_A: R5.2, U1.1
PGND: BR1.4 (-), C4.2, U3.1 (-Vin)
RAWP: BR1.1 (+), C4.1, J15.2, U3.2 (+Vin)
RLY1: M1.7 (GPIO32), R1.1
RLY1_B: Q1.2 (B), R1.2, R2.1
RLY2: M1.6 (GPIO33), R3.1
RLY2_B: Q2.2 (B), R3.2, R4.1
RTC_VBAT: BT3.1 (+), U5.14 (VBAT)
TAMPER: J5.1, M1.3 (GPIO27)
VBAT: BT1.1 (+), J13.1

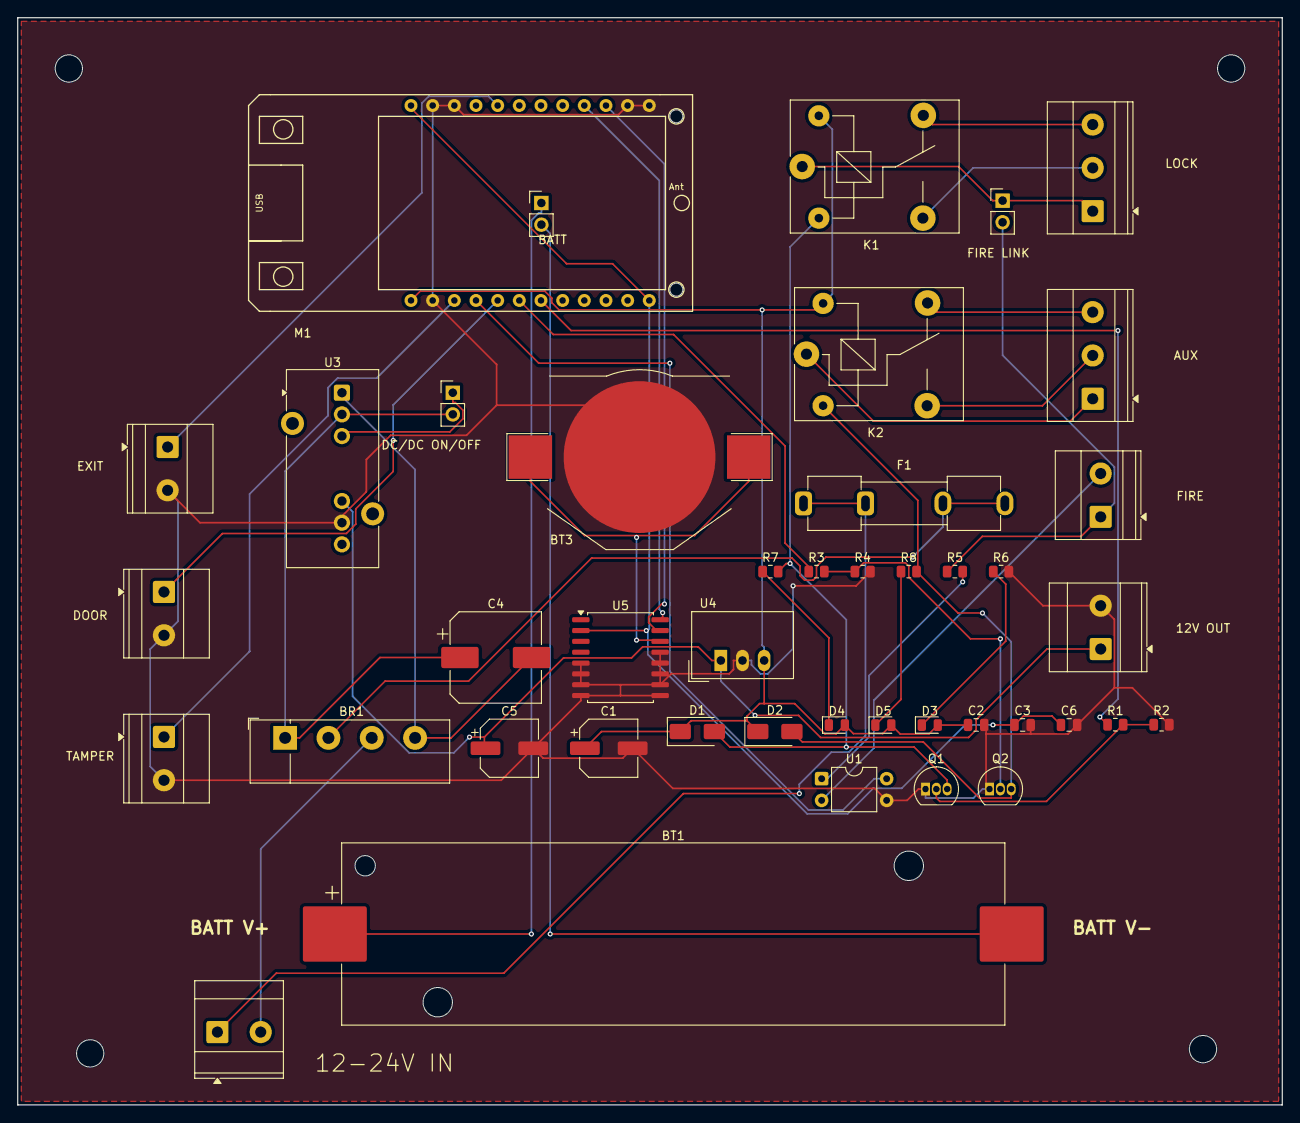
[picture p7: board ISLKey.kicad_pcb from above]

Board: 2 copper layers, 148.3 x 127.5 mm, 47 parts (0 on the bottom side), 37 nets.

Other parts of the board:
H1, H2, H3, H4: MountingHole_3.2mm_M3

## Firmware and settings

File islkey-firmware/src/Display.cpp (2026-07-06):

/**
 * Display.cpp — TTGO T-Display screen implementation
 */

#include "Display.h"

#ifdef BOARD_TTGO

#include <TFT_eSPI.h>
#include "Config.h"
#include "Inputs.h"   // for the input GPIO numbers shown on the inputs screen

// TTGO T-Display button GPIOs
#define BTN_TOP    0
#define BTN_BOTTOM 35
#define BACKLIGHT  4    // TFT backlight pin on TTGO

namespace Display {

    TFT_eSPI tft = TFT_eSPI();

    // ── State ──────────────────────────────────────────────────────────────────
    static char serial[24]     = "—";
    static char apPwd[16]      = "—";
    static char siteCode[16]   = "";
    static char doorName[64]   = "ISLKey Door";

    static char ssid[64]       = "";
    static char ipAddr[20]     = "0.0.0.0";
    static bool netConnected   = false;
    static int  rssi           = 0;

    static char apiHost[64]    = "(not set)";
    static bool apiOnline      = false;
    static char apiContact[24] = "never";
    static char apiEvent[40]   = "none";
    static char apiEventTime[24] = "";

    static bool bleConnected   = false;
    static char lastAccess[40] = "none";
    static bool lastGranted    = false;

    static bool doorOpen       = false;
    static bool fireAlarm      = false;
    static bool tamper         = false;
    static bool inLive[4]      = { false, false, false, false };   // real-time input triggered state

    static char timeStr[12]    = "--:--";

    static bool apActive       = false;
    static char apName[24]     = "ISLKey";

    // Full-screen provisioning status overlay (app/BLE provisioning)
    static bool provStatusActive = false;
    static char provLine1[28]    = "";
    static char provLine2[40]    = "";

    static int  currentScreen  = 0;
    static bool backlightOn    = true;

    static unsigned long lastDraw   = 0;
    static unsigned long lastBtnTop = 0;
    static unsigned long lastBtnBot = 0;
    static unsigned long flashUntil = 0;

    #define DRAW_INTERVAL_MS  500
    #define BTN_DEBOUNCE_MS   220

    // Colours (RGB565)
    #define C_BG      0x0821
    #define C_ACCENT  0x04FF
    #define C_GREEN   0x07E0
    #define C_RED     0xF800
    #define C_AMBER   0xFD00
    #define C_WHITE   0xFFFF
    #define C_MUTED   0x4A69
    #define C_DARK    0x1082

    const int NUM_SCREENS = 7;

    // ── Helpers ────────────────────────────────────────────────────────────────
    void setBacklight( bool on ) {
        backlightOn = on;
        analogWrite( BACKLIGHT, on ? 255 : 0 );
    }

    void drawHeader( const char* title ) {
        tft.fillRect( 0, 0, 240, 22, C_ACCENT );
        tft.setTextColor( C_WHITE, C_ACCENT );
        tft.setTextSize( 1 );
        tft.setCursor( 6, 7 );
        tft.print( title );
        tft.setCursor( 200, 7 );
        tft.print( timeStr );
    }

    void drawFooter() {
        tft.fillRect( 0, 118, 240, 17, C_DARK );
        tft.setTextColor( C_MUTED, C_DARK );
        tft.setTextSize( 1 );
        tft.setCursor( 6, 123 );
        tft.printf( "[%d/%d]  TOP:next  BOT:light", currentScreen + 1, NUM_SCREENS );
    }

    // label/value row helper
    void row( int y, const char* label, const char* value, uint16_t valCol = C_WHITE ) {
        tft.setTextSize( 1 );
        tft.setTextColor( C_MUTED, C_BG );
        tft.setCursor( 6, y );
        tft.print( label );
        tft.setTextColor( valCol, C_BG );
        tft.setCursor( 6, y + 11 );
        tft.print( value );
    }

    // ── Screen 0 : Identity ─────────────────────────────────────────────────────
    void drawIdentity() {
        tft.fillScreen( C_BG );
        drawHeader( "IDENTITY" );

        tft.setTextColor( C_MUTED, C_BG );
        tft.setTextSize( 1 );
        tft.setCursor( 6, 28 );
        tft.print( "Serial Number" );
        tft.setTextColor( C_ACCENT, C_BG );
        tft.setTextSize( 2 );
        tft.setCursor( 6, 39 );
        tft.print( serial );

        tft.setTextColor( C_MUTED, C_BG );
        tft.setTextSize( 1 );
        tft.setCursor( 6, 62 );
        tft.print( "Setup AP Password" );
        tft.setTextColor( C_AMBER, C_BG );
        tft.setTextSize( 2 );
        tft.setCursor( 6, 73 );
        tft.print( strlen( apPwd ) ? apPwd : "(open)" );

        tft.setTextSize( 1 );
        tft.setTextColor( C_MUTED, C_BG );
        tft.setCursor( 6, 98 );
        tft.print( "Door: " );
        tft.setTextColor( C_WHITE, C_BG );
        tft.print( doorName );
        tft.setTextColor( C_MUTED, C_BG );
        tft.setCursor( 6, 108 );
        tft.print( "Site: " );
        tft.setTextColor( C_WHITE, C_BG );
        tft.print( strlen( siteCode ) ? siteCode : "-" );

        drawFooter();
    }

    // ── Screen 1 : Door ──────────────────────────────────────────────────────────
    void drawDoor() {
        tft.fillScreen( C_BG );
        drawHeader( "DOOR STATUS" );

        tft.setTextColor( C_WHITE, C_BG );
        tft.setTextSize( 2 );
        tft.setCursor( 6, 28 );
        tft.print( doorName );

        tft.fillRect( 6, 52, 228, 30, doorOpen ? 0x6200 : 0x0320 );
        tft.setTextColor( doorOpen ? C_RED : C_GREEN, doorOpen ? 0x6200 : 0x0320 );
        tft.setTextSize( 2 );
        tft.setCursor( 12, 59 );
        tft.print( doorOpen ? "DOOR OPEN" : "DOOR CLOSED" );

        int y = 90;
        if ( fireAlarm ) {
            tft.fillRect( 6, y, 228, 20, 0x6200 );
            tft.setTextColor( C_RED, 0x6200 );
            tft.setTextSize( 1 );
            tft.setCursor( 12, y + 6 );
            tft.print( "!! FIRE ALARM ACTIVE" );
            y += 22;
        }
        if ( tamper ) {
            tft.fillRect( 6, y, 228, 20, 0x4200 );
            tft.setTextColor( C_AMBER, 0x4200 );
            tft.setTextSize( 1 );
            tft.setCursor( 12, y + 6 );
            tft.print( "!! TAMPER DETECTED" );
        }
        drawFooter();
    }

    // ── Screen 2 : Wi-Fi (setup AP mode or connected) ───────────────────────────
    void drawWiFi() {
        tft.fillScreen( C_BG );
        drawHeader( "WI-FI" );

        if ( apActive ) {
            // Provisioning / setup mode
            tft.fillRect( 6, 28, 228, 18, 0x4200 );
            tft.setTextColor( C_AMBER, 0x4200 );
            tft.setTextSize( 1 );
            tft.setCursor( 12, 34 );
            tft.print( "SETUP MODE - JOIN THIS NETWORK" );

            row( 50, "Network (SSID)", apName, C_WHITE );
            row( 74, "Password", strlen( apPwd ) ? apPwd : "(open)", C_AMBER );
            row( 98, "Then browse to", "http://192.168.4.1", C_ACCENT );
        } else {
            tft.fillRect( 6, 28, 90, 18, netConnected ? 0x0320 : C_DARK );
            tft.setTextColor( netConnected ? C_GREEN : C_MUTED,
                              netConnected ? 0x0320 : C_DARK );
            tft.setTextSize( 1 );
            tft.setCursor( 12, 34 );
            tft.print( netConnected ? "CONNECTED" : "OFFLINE" );

            row( 50, "Network (SSID)", strlen( ssid ) ? ssid : "(not set)", C_WHITE );

            tft.setTextColor( C_MUTED, C_BG );
            tft.setCursor( 6, 74 );
            tft.print( "IP Address" );
            tft.setTextColor( C_WHITE, C_BG );
            tft.setCursor( 6, 85 );
            tft.print( ipAddr );

            tft.setTextColor( C_MUTED, C_BG );
            tft.setCursor( 130, 74 );
            tft.print( "Signal" );
            uint16_t barCol = rssi > -60 ? C_GREEN : rssi > -75 ? C_AMBER : C_RED;
            tft.setTextColor( netConnected ? barCol : C_MUTED, C_BG );
            tft.setCursor( 130, 85 );
            if ( netConnected ) tft.printf( "%d dBm", rssi );
            else                tft.print( "--" );

            int barW = netConnected ? max( 4, min( 228, (rssi + 100) * 4 ) ) : 0;
            tft.fillRect( 6, 100, 228, 8, C_DARK );
            tft.fillRect( 6, 100, barW, 8, barCol );
        }
        drawFooter();
    }

    // ── Screen 3 : Cloud / API ──────────────────────────────────────────────────
    void drawCloud() {
        tft.fillScreen( C_BG );
        drawHeader( "CLOUD / API" );

        tft.fillRect( 6, 28, 90, 18, apiOnline ? 0x0320 : 0x6200 );
        tft.setTextColor( apiOnline ? C_GREEN : C_RED, apiOnline ? 0x0320 : 0x6200 );
        tft.setTextSize( 1 );
        tft.setCursor( 12, 34 );
        tft.print( apiOnline ? "ONLINE" : "OFFLINE" );

        row( 50, "Server", apiHost, C_WHITE );

        tft.setTextColor( C_MUTED, C_BG );
        tft.setCursor( 6, 74 );
        tft.print( "Last contact" );
        tft.setTextColor( C_WHITE, C_BG );
        tft.setCursor( 6, 85 );
        tft.print( apiContact );

        tft.setTextColor( C_MUTED, C_BG );
        tft.setCursor( 6, 98 );
        tft.print( "Last event" );
        tft.setTextColor( C_ACCENT, C_BG );
        tft.setCursor( 6, 108 );
        tft.print( apiEvent );
        if ( strlen( apiEventTime ) ) {
            tft.setTextColor( C_MUTED, C_BG );
            tft.print( "  " );
            tft.print( apiEventTime );
        }
        drawFooter();
    }

    // ── Screen 4 : BLE / Access ─────────────────────────────────────────────────
    void drawBLE() {
        tft.fillScreen( C_BG );
        drawHeader( "BLE / ACCESS" );

        tft.fillRect( 6, 28, 228, 22, bleConnected ? 0x000F : C_DARK );
        tft.setTextColor( bleConnected ? C_WHITE : C_MUTED,
                          bleConnected ? 0x000F : C_DARK );
        tft.setTextSize( 1 );
        tft.setCursor( 12, 35 );
        tft.print( bleConnected ? "BLE: PHONE CONNECTED" : "BLE: ADVERTISING" );

        tft.setTextColor( C_MUTED, C_BG );
        tft.setCursor( 6, 60 );
        tft.print( "Last access result" );
        tft.setTextColor( lastGranted ? C_GREEN : C_RED, C_BG );
        tft.setTextSize( 2 );
        tft.setCursor( 6, 72 );
        tft.print( lastGranted ? "GRANTED" : "DENIED" );

        tft.setTextSize( 1 );
        tft.setTextColor( C_WHITE, C_BG );
        tft.setCursor( 6, 98 );
        tft.print( lastAccess );

        drawFooter();
    }

    // ── Screen 5 : Inputs ────────────────────────────────────────────────────────
    void drawInputs() {
        tft.fillScreen( C_BG );
        drawHeader( "SECURITY INPUTS" );

        const char* fn_labels[] = { "Disabled", "Exit Button", "Door Contact", "Fire Alarm", "Tamper" };
        const int   inPins[4]   = { INPUT_1_PIN, INPUT_2_PIN, INPUT_3_PIN, INPUT_4_PIN };

        for ( int i = 0; i < 4; i++ ) {
            int y = 28 + (i * 22);
            InputFunction fn = Config::inputs[i].function;
            bool trig = inLive[i];                       // real-time pin state
            bool disabled = ( fn == INPUT_DISABLED );

            uint16_t bg = disabled ? C_DARK : ( trig ? 0x6200 : 0x0320 );  // red if triggered, green if clear
            tft.fillRect( 6, y, 228, 20, bg );

            // Label: IN1 (G13) Exit Button
            tft.setTextSize( 1 );
            tft.setTextColor( C_WHITE, bg );
            tft.setCursor( 12, y + 6 );
            tft.printf( "IN%d G%d %s", i + 1, inPins[i], fn_labels[fn] );

            // Live status pill on the right
            const char* st = disabled ? "—" : ( trig ? "TRIGGERED" : "CLEAR" );
            uint16_t stc   = disabled ? C_MUTED : ( trig ? C_RED : C_GREEN );
            tft.setTextColor( stc, bg );
            tft.setCursor( 168, y + 6 );
            tft.print( st );
        }
        drawFooter();
    }

    // ── Screen 6 : Device ────────────────────────────────────────────────────────
    void drawDevice() {
        tft.fillScreen( C_BG );
        drawHeader( "DEVICE INFO" );

        row( 28, "Firmware / Board", "v1.0.0  TTGO T-Display", C_WHITE );
        row( 52, "IP Address", apActive ? "192.168.4.1 (AP)" : ipAddr, C_WHITE );

        unsigned long upSec  = millis() / 1000;
        char uptimeBuf[24];
        snprintf( uptimeBuf, sizeof(uptimeBuf), "%luh %02lum %02lus",
                  upSec / 3600, (upSec % 3600) / 60, upSec % 60 );
        row( 76, "Uptime", uptimeBuf, C_WHITE );

        char heapBuf[24];
        snprintf( heapBuf, sizeof(heapBuf), "%u KB free", (unsigned)(ESP.getFreeHeap() / 1024) );
        row( 100, "Memory", heapBuf, C_WHITE );

        drawFooter();
    }

    void drawProvStatus() {
        tft.fillScreen( C_BG );
        tft.fillRect( 0, 0, 240, 22, C_ACCENT );
        tft.setTextColor( C_WHITE, C_ACCENT );
        tft.setTextSize( 1 );
        tft.setCursor( 6, 7 );
        tft.print( "PROVISIONING" );

        tft.setTextColor( C_WHITE, C_BG );
        tft.setTextSize( 2 );
        tft.setCursor( 10, 48 );
        tft.print( provLine1 );

        if ( provLine2[0] ) {
            tft.setTextColor( C_MUTED, C_BG );
            tft.setTextSize( 1 );
            tft.setCursor( 10, 80 );
            tft.print( provLine2 );
        }
    }

    void drawCurrentScreen() {
        if ( millis() < flashUntil ) return;   // flash has priority
        if ( provStatusActive ) { drawProvStatus(); return; }  // overrides all screens
        switch ( currentScreen ) {
            case 0: drawIdentity(); break;
            case 1: drawDoor();     break;
            case 2: drawWiFi();     break;
            case 3: drawCloud();    break;
            case 4: drawBLE();      break;
            case 5: drawInputs();   break;
            case 6: drawDevice();   break;
        }
    }

    // ── Lifecycle ────────────────────────────────────────────────────────────────
    void init() {
        pinMode( BTN_TOP,    INPUT_PULLUP );
        pinMode( BTN_BOTTOM, INPUT_PULLUP );
        pinMode( BACKLIGHT,  OUTPUT );
        setBacklight( true );

        tft.init();
        tft.setRotation( 1 );    // landscape, 240x135
        tft.fillScreen( C_BG );

        // Boot splash
        tft.setTextColor( C_ACCENT, C_BG );
        tft.setTextSize( 3 );
        tft.setCursor( 40, 34 );
        tft.print( "ISLKey" );
        tft.setTextSize( 1 );
        tft.setTextColor( C_MUTED, C_BG );
        tft.setCursor( 40, 72 );
        tft.print( "Access Control Platform" );
        tft.setCursor( 40, 86 );
        tft.print( "ISL Technologies" );

        strncpy( doorName, Config::device.door_name, sizeof(doorName) );
        strncpy( siteCode, Config::device.site_code, sizeof(siteCode) );
        if ( strlen( Config::device.serial ) ) strncpy( serial, Config::device.serial, sizeof(serial) );
        if ( strlen( Config::device.ap_pwd ) ) strncpy( apPwd,  Config::device.ap_pwd,  sizeof(apPwd) );

        Serial.println("[DISPLAY] Initialised");
        delay( 1500 );
    }

    void showAccessFlash( bool granted ) {
        tft.fillScreen( granted ? C_GREEN : C_RED );
        tft.setTextColor( C_BG, granted ? C_GREEN : C_RED );
        tft.setTextSize( 3 );
        tft.setCursor( granted ? 40 : 50, 50 );
        tft.print( granted ? "GRANTED" : "DENIED" );
        flashUntil = millis() + 1500;
    }

    void loop() {
        unsigned long now = millis();

        if ( flashUntil > 0 && now > flashUntil ) {
            flashUntil = 0;
            drawCurrentScreen();
        }

        if ( digitalRead( BTN_TOP ) == LOW ) {
            if ( now - lastBtnTop > BTN_DEBOUNCE_MS ) {
                lastBtnTop = now;
                currentScreen = ( currentScreen + 1 ) % NUM_SCREENS;
                drawCurrentScreen();
            }
        }

        if ( digitalRead( BTN_BOTTOM ) == LOW ) {
            if ( now - lastBtnBot > BTN_DEBOUNCE_MS ) {
                lastBtnBot = now;
                setBacklight( !backlightOn );
            }
        }

        if ( now - lastDraw > DRAW_INTERVAL_MS && flashUntil == 0 ) {
            lastDraw = now;
            drawCurrentScreen();
        }
    }

    // ── Setters ──────────────────────────────────────────────────────────────────
    void setIdentity( const char* s, const char* p, const char* sc ) {
        if ( s && strlen(s) ) strncpy( serial, s, sizeof(serial) );
        if ( p && strlen(p) ) strncpy( apPwd,  p, sizeof(apPwd) );
        if ( sc ) strncpy( siteCode, sc, sizeof(siteCode) );
    }
    void setDoorName( const char* n ) { strncpy( doorName, n, sizeof(doorName) ); }
    void setWiFi( const char* s, bool c, const char* ip, int r ) {
        strncpy( ssid, s, sizeof(ssid) );
        netConnected = c;
        strncpy( ipAddr, ip, sizeof(ipAddr) );
        rssi = r;
    }
    void setCloud( const char* h, bool online, const char* contact,
                   const char* ev, const char* evTime ) {
        strncpy( apiHost, h, sizeof(apiHost) );
        apiOnline = online;
        strncpy( apiContact, contact, sizeof(apiContact) );
        strncpy( apiEvent, ev, sizeof(apiEvent) );
        strncpy( apiEventTime, evTime, sizeof(apiEventTime) );
    }
    void setProvisioningStatus( const char* line1, const char* line2 ) {
        if ( line1 == nullptr ) {
            provStatusActive = false;
            lastDraw = 0;           // force a normal redraw next loop
            return;
        }
        provStatusActive = true;
        strncpy( provLine1, line1, sizeof(provLine1) - 1 );
        provLine1[ sizeof(provLine1) - 1 ] = '\0';
        provLine2[0] = '\0';
        if ( line2 ) {
            strncpy( provLine2, line2, sizeof(provLine2) - 1 );
            provLine2[ sizeof(provLine2) - 1 ] = '\0';
        }
        flashUntil = 0;
        drawProvStatus();           // show immediately
    }

    void setBLEStatus( bool c ) { bleConnected = c; }
    void setLastAccess( const char* ev, bool g ) {
        strncpy( lastAccess, ev, sizeof(lastAccess) );
        lastGranted = g;
    }
    void setInputStates( bool d, bool f, bool t ) {
        doorOpen = d; fireAlarm = f; tamper = t;
    }
    void setInputLive( bool i1, bool i2, bool i3, bool i4 ) {
        inLive[0] = i1; inLive[1] = i2; inLive[2] = i3; inLive[3] = i4;
    }
    void setTime( struct tm* ti ) {
        snprintf( timeStr, sizeof(timeStr), "%02d:%02d", ti->tm_hour, ti->tm_min );
    }
    void setProvisioning( bool inAP, const char* name ) {
        apActive = inAP;
        if ( name ) strncpy( apName, name, sizeof(apName) );
    }
}

#endif // BOARD_TTGO

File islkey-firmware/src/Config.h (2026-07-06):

/**
 * Config.h — NVS-backed configuration storage
 * Stores all provisioning settings in ESP32 non-volatile storage
 */

#pragma once
#include <Preferences.h>
#include <Arduino.h>

// Input function types
enum InputFunction {
    INPUT_DISABLED    = 0,
    INPUT_EXIT_BTN    = 1,
    INPUT_DOOR_CONTACT= 2,
    INPUT_FIRE_ALARM  = 3,
    INPUT_TAMPER      = 4,
};

// Input logic
enum InputLogic {
    LOGIC_NC = 0,   // Normally Closed — LOW=secure, HIGH=triggered
    LOGIC_NO = 1,   // Normally Open   — HIGH=secure, LOW=triggered
};

// Relay function
enum RelayFunction {
    RELAY_DISABLED    = 0,
    RELAY_PRIMARY_LOCK= 1,
    RELAY_SECONDARY   = 2,
    RELAY_ALARM_OUT   = 3,
};

// Fail safe mode
enum FailSafe {
    FAIL_LOCKED = 0,
    FAIL_OPEN   = 1,
};

struct InputConfig {
    InputFunction function;
    InputLogic    logic;
};

struct RelayConfig {
    RelayFunction function;
    uint16_t      pulse_ms;      // How long relay energises for unlock (ms)
    bool          active_high;   // true = HIGH energises relay
};

struct DoorConfig {
    uint16_t held_open_secs;     // Alert if door open longer than this
    bool     forced_entry_detect;// Alert if door opens without valid access
};

struct DeviceConfig {
    char door_name[64];
    char site_code[16];
    char serial[24];        // Factory serial e.g. ISL-0006-20260614 (set via commissioning)
    char ap_pwd[16];        // Provisioning AP password (set via commissioning)
    char device_uuid[40];   // Server-assigned at /device/register
    char hmac_secret[80];   // HMAC-SHA256 key from /device/register (64 hex chars)
};

struct NetworkConfig {
    char wifi_ssid[64];
    char wifi_password[64];
    char api_url[128];
    char api_token[128];
};

namespace Config {

    extern InputConfig  inputs[4];
    extern RelayConfig  relays[2];
    extern DoorConfig   door;
    extern DeviceConfig device;
    extern NetworkConfig network;

    void init();
    void clear();
    void save();
    bool isProvisioned();

    // Individual setters called from provisioning page
    void setNetwork( const char* ssid, const char* pass, const char* url, const char* token );
    void setInput( int idx, InputFunction fn, InputLogic logic );
    void setRelay( int idx, RelayFunction fn, uint16_t pulse_ms, bool active_high );
    void setDoor( uint16_t held_open_secs, bool forced_entry );
    void setDevice( const char* name, const char* site_code );

    // Factory identity written by the flasher over serial (commissioning).
    // Persists in NVS independently of provisioning.
    void setIdentity( const char* serial, const char* ap_pwd );

    // Apply a full commissioning payload (compact JSON from the .islkey file):
    // serial, ap_pwd, api_url, api_token, door_name, site_code. Persists to NVS
    // WITHOUT marking the unit provisioned — WiFi is still entered on the device.
    void applyCommissionJson( const char* json );

    // Device credentials returned by /device/register (persisted to NVS).
    void setDeviceCreds( const char* device_uuid, const char* hmac_secret );
}

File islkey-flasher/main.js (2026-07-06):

/**
 * ISLKey Flasher v1.1.0 — Electron Main Process
 * Adds: serial number generation, random AP password,
 *       CSV asset register, TTGO T-Display support,
 *       WT32-ETH01 Ethernet board support
 */

const { app, BrowserWindow, ipcMain, shell, dialog } = require('electron');
const path   = require('path');
const fs     = require('fs');
const { spawn, execFileSync } = require('child_process');
const { SerialPort } = require('serialport');

let mainWindow;

// ── Resource paths ─────────────────────────────────────────────────────────────
function resourcePath(...parts) {
    if (app.isPackaged) return path.join(process.resourcesPath, ...parts);
    return path.join(__dirname, ...parts);
}

const ESPTOOL_PATH  = resourcePath('bin', 'esptool.exe');
const FIRMWARE_DIR  = resourcePath('firmware');
// Serial register + counter must SURVIVE app updates/uninstalls — keep them in the
// persistent user-data dir, not in the install folder (which is replaced on update).
const SERIALS_DIR   = app.isPackaged
    ? path.join(app.getPath('userData'), 'serials')
    : resourcePath('serials');
const SERIAL_CSV    = path.join(SERIALS_DIR, 'isl-serial-register.csv');
const SERIAL_COUNTER= path.join(SERIALS_DIR, 'next-serial.txt');

// ── Ensure serials directory exists ───────────────────────────────────────────
function ensureSerialsDir() {
    if (!fs.existsSync(SERIALS_DIR)) fs.mkdirSync(SERIALS_DIR, { recursive: true });
    if (!fs.existsSync(SERIAL_CSV)) {
        fs.writeFileSync(SERIAL_CSV,
            'serial_number,board_type,firmware,flash_date,ap_password,door_name,site_code,api_url,notes\r\n'
        );
    }
    if (!fs.existsSync(SERIAL_COUNTER)) {
        fs.writeFileSync(SERIAL_COUNTER, '1');
    }
}

// ── Serial number generation ───────────────────────────────────────────────────
function generateSerial() {
    ensureSerialsDir();
    const next = parseInt(fs.readFileSync(SERIAL_COUNTER, 'utf8').trim()) || 1;
    const date = new Date();
    const dateStr = `${date.getFullYear()}${
        String(date.getMonth()+1).padStart(2,'0')}${
        String(date.getDate()).padStart(2,'0')}`;
    const serial = `ISL-${String(next).padStart(4,'0')}-${dateStr}`;
    fs.writeFileSync(SERIAL_COUNTER, String(next + 1));
    return serial;
}

// ── Random AP password ─────────────────────────────────────────────────────────
function generateAPPassword() {
    const chars = 'ABCDEFGHJKLMNPQRSTUVWXYZ23456789'; // No O,0,I,1 — confusing
    let pwd = '';
    for (let i = 0; i < 8; i++) {
        pwd += chars[Math.floor(Math.random() * chars.length)];
    }
    return pwd;
}

// ── Log to CSV register ────────────────────────────────────────────────────────
function logToCSV({ serial, boardType, firmware, apPassword, doorName = '', siteCode = '', apiUrl = '', notes = '' }) {
    ensureSerialsDir();
    const date = new Date().toISOString();
    const row  = `${serial},"${boardType}","${firmware}","${date}","${apPassword}","${doorName}","${siteCode}","${apiUrl}","${notes}"\r\n`;
    fs.appendFileSync(SERIAL_CSV, row);
}

// ── Window ─────────────────────────────────────────────────────────────────────
function createWindow() {
    mainWindow = new BrowserWindow({
        width: 900, height: 720,
        minWidth: 760, minHeight: 600,
        frame: false,
        backgroundColor: '#0a0e17',
        webPreferences: {
            preload: path.join(__dirname, 'preload.js'),
            nodeIntegration: false,
            contextIsolation: true,
        },
        icon: path.join(__dirname, 'assets', 'icon.ico'),
        title: 'ISLKey Flasher',
    });
    mainWindow.loadFile(path.join(__dirname, 'renderer', 'index.html'));
    mainWindow.on('closed', () => { mainWindow = null; });
}

app.whenReady().then(() => { ensureSerialsDir(); createWindow(); });
app.on('window-all-closed', () => { if (process.platform !== 'darwin') app.quit(); });

// ── IPC: Window controls ───────────────────────────────────────────────────────
ipcMain.handle('window-minimize', () => mainWindow?.minimize());
ipcMain.handle('window-maximize', () => {
    mainWindow?.isMaximized() ? mainWindow.unmaximize() : mainWindow?.maximize();
});
ipcMain.handle('window-close', () => app.quit());

// ── IPC: Serial ports ──────────────────────────────────────────────────────────
ipcMain.handle('list-ports', async () => {
    try {
        const ports = await SerialPort.list();
        return ports.map(p => ({
            path:         p.path,
            friendlyName: p.friendlyName || p.path,
            manufacturer: p.manufacturer || '',
        }));
    } catch(e) { return []; }
});

// ── IPC: Firmware files ────────────────────────────────────────────────────────
ipcMain.handle('list-firmware', async () => {
    try {
        if (!fs.existsSync(FIRMWARE_DIR)) return [];
        return fs.readdirSync(FIRMWARE_DIR)
            .filter(f => f.endsWith('.bin'))
            .map(f => {
                const full = path.join(FIRMWARE_DIR, f);
                const stat = fs.statSync(full);
                // Parse board type hint from filename e.g. islkey-relay-v1.0.0.bin
                let boardHint = 'all';
                if (f.includes('relay'))  boardHint = 'relay-board';
                if (f.includes('devkit')) boardHint = 'devkit';
                if (f.includes('ttgo') || f.includes('display')) boardHint = 'ttgo';
                if (f.includes('eth') || f.includes('wt32'))     boardHint = 'wt32-eth01';
                return {
                    name:      f,
                    path:      full,
                    sizekb:    Math.round(stat.size / 1024),
                    boardHint,
                };
            });
    } catch(e) { return []; }
});

// ── IPC: Generate serial + password ───────────────────────────────────────────
ipcMain.handle('generate-serial', async () => {
    return {
        serial:     generateSerial(),
        apPassword: generateAPPassword(),
    };
});

// ── IPC: Read the PC's current WiFi (SSID + saved password) ───────────────────
ipcMain.handle('get-pc-wifi', async () => {
    try {
        const ifOut = execFileSync('netsh', ['wlan', 'show', 'interfaces'], { encoding: 'utf8' });
        const m = ifOut.match(/^\s*SSID\s*:\s*(.+?)\s*$/m);   // not BSSID — ^\s* anchors to line start
        const ssid = m ? m[1].trim() : '';
        if (!ssid) return { ok: false, error: 'No active WiFi connection on this PC.' };

        let password = '';
        try {
            const pOut = execFileSync('netsh', ['wlan', 'show', 'profile', `name=${ssid}`, 'key=clear'], { encoding: 'utf8' });
            const pm = pOut.match(/Key Content\s*:\s*(.+?)\s*$/m);
            password = pm ? pm[1].trim() : '';
        } catch (e) { /* password not retrievable (e.g. enterprise/open) */ }

        return { ok: true, ssid, password };
    } catch (e) {
        return { ok: false, error: 'Could not read WiFi: ' + e.message };
    }
});
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

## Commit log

2026-07-06 Initial commit — ISLKey access-control platform
    Firmware (ESP32/PlatformIO, 4 targets), Electron flasher/commissioning
    tool, Flutter companion app, KiCad schematic, and wiring-diagram generators.
    Claude-Session: https://claude.ai/code/session_01WaJbCVpNNC7xF4fkqWpjpA
    [ISLKey.kicad_sch]
2026-07-28 kicad: rebuild ISLKey TTGO carrier as a real, manufacturable design
    Replace the box-symbol connectivity sketch with a proper KiCad 10 design
    generated from gen/ scripts that embed genuine library symbols (correct
    pin<->pad maps) with footprints assigned:
    - Schematic (ISLKey.kicad_sch): 40 parts, ERC 0/0. TTGO T-Display carrier
    with dual onboard SANYOU-SRD relays (2N2222 drivers, flyback, green status
    LED across each coil), monitored fire link (PC817 + COM<->fire jumper),
    wide-input isolated PSU (5-60V AC/DC -> KBU bridge + fuse -> isolated 12V
    DC-DC module -> 12->5V buck), 12V lock/aux output, and 18650 battery
    passthrough. PGND/GND kept separate to preserve isolation.
    - PCB (ISLK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
    [ISLKey-BOM.csv, ISLKey.kicad_pcb, ISLKey.kicad_sch]
2026-07-28 kicad: use real Traco parts for the wide-input PSU
    Replace the two generic module-header placeholders with genuine parts +
    KiCad footprints:
    - U3 isolated 12V: Traco TEN20-2412WIN (9-36V in -> isolated 12V/20W),
    footprint Converter_DCDC_TRACO_TEN20-xxxx_THT. Remote pin left open
    (positive logic, open = ON); Trim pin NC.
    - U4 buck 12->5V for the TTGO: Traco TSR-1-2450 (SIP-3), footprint
    Converter_DCDC_TRACO_TSR-1_THT.
    - Add PWR_FLAG on the raw primary rails (RAWP/PGND) so ERC sees them driven
    (bridge diode outputs are 'passive'); flags excluded from board + BOM.
    ERC 0/0, DRC 0 (unrouted ratsnest only). One board covers 12/24V systems;
    pin-compatible TEN20-4812WIN swaps in for 48V.
    C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
    [ISLKey-BOM.csv, ISLKey.kicad_pcb, ISLKey.kicad_sch]
2026-07-28 kicad: real TTGO T-Display footprint + routing-aware placement
    - Replace the two guessed 1x12 header sockets with a single correct TTGO
    T-Display module footprint + symbol (from GillesOdb/ttgo-tdisplay-kicad,
    legacy .kicad_mod + .lib converted to KiCad 10). Confirms the 22.86mm
    header row spacing. Pad<->GPIO verified against the module pinout
    (pad7=GPIO32, 6=GPIO33, 5=GPIO25, 4=GPIO26, 3=GPIO27, 20=GPIO13,
    1=5V, 2/13/14/22/23=GND, 12/24=3V3); symbol pins retyped passive.
    - Local libs: lib/ISLKey.pretty + lib/ISLKey.kicad_sym, with project
    fp-lib-table / sym-lib-table so KiCad resolves them.
    - make_pcb.py: routing-aware floorplan (inputs on left edge, TTGO centre,
    each relay dri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
    [ISLKey-BOM.csv, ISLKey.kicad_pcb, ISLKey.kicad_sch]
2026-07-28 kicad: place battery pads (J13) between the TTGO header rows
    The TTGO battery lead emerges between the two header rows, so centre the
    2 solder pads (VBAT/GND_BAT) on M1's pad centroid rather than at the board
    edge. J14 (18650-pack screw terminal) stays on the left edge; no on-board
    holder (external holder via J14). DRC unchanged (no physical collisions).
    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
    [ISLKey.kicad_pcb]
2026-07-28 kicad: add RTC (DS3231), on-board 2x18650 holders, and ground pour
    - RTC: DS3231M (I2C on GPIO21/22 via the TTGO's onboard pull-ups),
    CR2032-backed (Keystone 3002) + 100nF. PWR_FLAGs on +3V3/RTC_VBAT.
    - Battery: two Keystone 1042 1x18650 holders in parallel (BT1/BT2) on
    VBAT/GND_BAT, replacing the external-holder terminal (J14 removed).
    - Ground plane: GND-filled zones on F.Cu and B.Cu (fill done on a reloaded
    board -- filling the freshly-built in-memory board segfaults pcbnew).
    ERC 0/0, DRC no physical collisions (cosmetic silk/text-height only).
    Board grows to ~219x200mm from the 18650 holders.
    Claude-Session: https://claude.a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
    [ISLKey-BOM.csv, ISLKey.kicad_pcb, ISLKey.kicad_sch]
2026-07-29 kicad: pack the board tight (219x200 -> 141x156mm)
    The old placement spaced parts by their SILK-TEXT bounding box (values like
    "5-60V AC/DC IN" rendered ~53mm wide), leaving the board mostly empty. Fix:
    - hide value silk; pack by the text-excluded body bbox GetBoundingBox(False,False)
    - First-Fit-Decreasing-Height shelf pack (similar-height parts share a row)
    - batteries broken out into their own block (78mm holders no longer inflate
    every shelf)
    Board 140.9x155.7mm (was 219x200); circuit-only w/o the 18650s ~133x114.
    Trade-off: this is size-optimised, grouped by height not signal flow -- final
    routable arrangement is a GUI step. ERC 0, DRC no physical collisions.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
    [ISLKey.dsn, ISLKey.kicad_pcb]
2026-07-29 kicad: single 18650 backup cell (was 2x)
    Drop to one Keystone 1042 18650 holder (BT1) on VBAT/GND_BAT -> 3.7V straight
    to the TTGO LiPo input (no series/parallel question, ~3000mAh covers the 7h
    backup target). Board 140.9x132mm.
    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
    [ISLKey-BOM.csv, ISLKey.kicad_pcb, ISLKey.kicad_sch]
2026-07-29 kicad: autoroute the board (Freerouting) -- 262 traces + 9 vias
    Full copper route via Freerouting 2.2.4 (portable JRE25, headless batch):
    export Specctra DSN -> autoroute -> import SES. Placement loosened to
    GAP=4mm/W=140 (148x153mm) for routing channels; net classes trimmed to
    Power 0.4mm / Lock 0.6mm so the wide nets fit. GND pour set to solid pad
    connection on both layers.
    Result: 62 nets routed, DRC clean bar cosmetic silk-height (imported TTGO
    footprint) + one RTC (U5) ground pin needing a manual via in a congested
    spot. Board-gen quirk noted in-code: ExportSpecctraDSN won't overwrite an
    existing file -- delete first.
    Claude-Sess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
    [ISLKey.dsn, ISLKey.kicad_pcb]
2026-07-29 kicad: SMD passives, perimeter terminals, fully routed on user's placement
    - Passives -> SMD (assembly-house placeable): R/LED 0805, ceramics 0805,
    flyback diodes SMA, electrolytics SMD alu (100V bulk on 10mm can).
    - Fixed the Traco TEN20 footprint's buggy 51mm courtyard -> local
    lib/ISLKey.pretty/TEN20_TRACO (~26mm).
    - User hand-placed the board in KiCad (terminals on the perimeter, USB-C
    clear, ~1/3 smaller). Repaired the malformed outline into a clean rect
    enclosing the corner mounting holes (148x128mm), redrew GND pours.
    - Routed with Freerouting exporting the DSN WITHOUT the pour so GND routes
    as traces (avoids isolated pour-island unconnects): 368 traces + 22 vias,
    0 unrout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
    [ISLKey-BOM.csv, ISLKey.kicad_pcb, ISLKey.kicad_sch]
2026-07-29 kicad: swap isolated DC-DC to Traco TMR10-2412WIR (was TEN20, too big)
    TEN20-2412WIN (25.4x25.4mm 20W 1"x1" brick) -> TMR10-2412WIR (13.7x23.6mm,
    10W, 9-36V->isolated 12V) -- ~half the area, powers logic + a ~6W lock.
    Rewired U3 (1=-Vin/PGND, 2=+Vin/RAWP, 3=Remote NC=on, 6=+Vout/12V,
    7=-Vout/GND, 9/10=Case NC). Footprint swapped in place on the hand-placed
    board, re-routed (GND-as-traces): 328 traces + 25 vias, DRC clean bar
    cosmetic silk text-height.
    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
    [ISLKey-BOM.csv, ISLKey.kicad_pcb, ISLKey.kicad_sch]
2026-07-29 kicad: add TMR10 Ctrl/Remote enable jumper (J15)
    2-pin jumper J15 links U3 pin3 (Ctrl/Remote, net DCDC_CTRL) to +Vin (RAWP):
    fit the shunt to tie Ctrl->+Vin (forces ON regardless of the module's logic
    polarity); leave open = ON for positive-logic parts. Placed in the space
    freed by the smaller TMR10; re-routed (356 traces + 26 vias, DRC clean bar
    cosmetic silk).
    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
    [ISLKey-BOM.csv, ISLKey.kicad_pcb, ISLKey.kicad_sch]
2026-07-29 kicad: fix U3/F1 3D models + add functional silk labels
    - 3D: TMR10 and Keystone-3512 fuse-holder .step models aren't in this KiCad
    3D package (referenced files absent). Repointed U3 -> generic
    Converter_DCDC_TRACO_TMR-xxxx and F1 -> Fuseholder_Cylinder-5x20mm_Schurter
    (both exist) so they render (approximate stand-ins).
    - Silk: added functional labels on F.SilkS at each terminal/jumper
    (EXIT/DOOR/TAMPER/LOCK/AUX/FIRE/5-60V IN/12V OUT/FIRE LINK/DCDC ON/BATT)
    and hid the Jxx refdes on those parts. Remaining silk_overlap DRC is
    cosmetic (silk-to-silk on a dense board).
    Claude-Session: https://claude.ai/code/session_01WaJbCVpN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
    [ISLKey.kicad_pcb]
2026-07-29 kicad: fix broken DCDC_CTRL jumper net + re-route
    The U3->TMR10 swap never assigned U3 pin3, so the DCDC_CTRL net didn't exist
    and J15 (the enable jumper) connected to nothing. Re-synced all pad nets from
    the schematic manifest (only U3.3/J15.1 differed) and re-routed: 346 traces +
    23 vias, 0 unconnected. User's silk edits preserved. DRC = cosmetic only.
    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
    [ISLKey.kicad_pcb]
2026-07-29 kicad: PCBWay manufacturing package (gerbers, drill, CPL, BOM)
    2-layer, 148.4x127.6mm, 43 components. Standard fab layers + F/B paste,
    Excellon drill, gerber job, pick-and-place CPL, BOM, and README-FAB with
    specs + assembly notes (MPNs still needed for turnkey PCBA; M1 module fits
    post-assembly). Zipped to ISLKey-PCBWay.zip.
    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
    [ISLKey-BOM.csv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]
2026-07-29 kicad: turnkey BOM with MPNs + distributor part numbers
    ISLKey-BOM-turnkey.csv: manufacturer + MPN + distributor PN for every
    placed part (M1/TTGO omitted - customer-sourced). Covers passives (Yageo/
    Samsung/Panasonic/Nichicon), relays (Songle SRD-05VDC-SL-C), DC-DC (Traco
    TMR10-2412WIR + TSR 1-2450), RTC (DS3231SN - flags that the 16-SOIC part is
    SN not the SO-8 'M'), bridge (KBU4M), Phoenix MKDS terminals (1715721/
    1715734), Keystone holders (1042/3002), fuse + clips, headers + shunts.
    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
    [ISLKey-BOM-turnkey.csv]
2026-07-29 Release v1.0.0 — ISLKey 1-MDC
    Freeze the full-featured controller as v1.0.0 "1-MDC": TTGO carrier, 4 inputs
    (exit/door/fire/tamper), dual relays w/ status LEDs, monitored fire link,
    DS3231 RTC, single 18650 backup, wide-input isolated PSU (TMR10 -> TSR buck),
    SMD passives, perimeter terminals, fully routed (148x128mm), turnkey BOM +
    PCBWay package.
    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
    [ISLKey.kicad_sch]
2026-07-29 mini: 1-MINI (v2.0.0) schematic — single-relay 1-gang controller
    New stripped design for a UK 1-gang back box: TTGO + 1 lock relay (Omron G6E
    2A, dry COM/NO/NC) + 1 exit input + non-isolated 12VAC/DC->5V (Diotec ABS
    bridge -> AP63203 buck). All-SMD except relay/TTGO/terminals. Low-profile
    Phoenix PT-3.5-H horizontal terminals. gen/make_mini_sch.py -> mini/ folder
    (1-MDC untouched). ERC 0.
    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
    [ISLKey-Mini-BOM.csv, ISLKey-Mini.kicad_sch]
2026-07-29 mini: 1-MINI PCB routed (60x60mm, 1-gang back box)
    Placed + routed the mini: 60x60mm outline with semicircular screw notches on
    L/R edges (back-box fixing screws ~62mm centres). TTGO across the bottom,
    relay top-left, terminals in a top-right row, power across the middle. GND
    pour both layers, GND-as-traces route: 170 traces + 3 vias, 0 unconnected,
    DRC clean bar cosmetic silk. gen/make_mini_pcb.py.
    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
    [ISLKey-Mini.kicad_pcb]
2026-07-29 mini: add 8mm hole above the TTGO + re-route
    8mm Edge.Cuts cutout, horizontally centred at (30,28) - just above the TTGO,
    slightly above board-centre. Moved D3/R4 clear of it; re-routed around the
    hole (171 traces + 4 vias, 0 unconnected); GND pours auto-clip to the cutout.
    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
    [ISLKey-Mini.kicad_pcb]
2026-07-29 mini: terminal silk labels + PCBWay package
    Silk labels 12V/LOCK/EXIT on the terminals (+ RELAY). Full PCBWay package:
    gerbers + drill + paste + CPL + BOM + turnkey BOM (MPNs) + fab readme noting
    the 1-gang screw notches and 8mm cutout. Zipped to ISLKey-Mini-PCBWay.zip.
    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
    [ISLKey-Mini-BOM-turnkey.csv, ISLKey-Mini-BOM.csv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]
2026-07-29 mini: add ISL logo + back silk text; regenerate PCBWay package
    - Board (1-MINI, V2.0.0): user-placed 12mm ISL logo footprint on the
    back silk plus back text ("1-Mini" + company line).
    - Regenerated the full PCBWay package from the edited board with zones
    refilled and silk-over-mask clipping: 9 .gbr layers, PTH+NPTH drill,
    gerber job file. Back silkscreen now contains the logo + text.
    - Verified pre-ship: 0 unconnected pads (fully routed); schematic net
    parity clean except the TTGO's unused GPIO pins (floating by design);
    no electrical/clearance/short DRC. Remaining flags are cosmetic silk.
    - Untrack scratch (drc.txt, .kicad_prl); ignore .lck and stray
    project-folder footprint cop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
    [ISLKey-Mini-B_Cu.gbr, ISLKey-Mini-B_Mask.gbr, ISLKey-Mini-B_Paste.gbr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]
2026-07-30 mini: add MPNs to main BOM, drop stale phantom D6
    ISLKey-Mini-BOM.csv now carries Manufacturer/MPN/Supplier/Supplier-PN
    columns for all 25 board parts (matched to the schematic + PCB, which
    agree). Removed D6/SS34, a leftover from an older schematic revision no
    longer in the design. M1 (TTGO) listed as DNP/customer-sourced.
    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
    [ISLKey-Mini-BOM.csv]
